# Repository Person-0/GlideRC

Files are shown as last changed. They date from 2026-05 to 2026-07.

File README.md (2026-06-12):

# **GlideRC**
Transforming a 2$ hand-thrown foam glider into an RC Airplane.
<br><br>
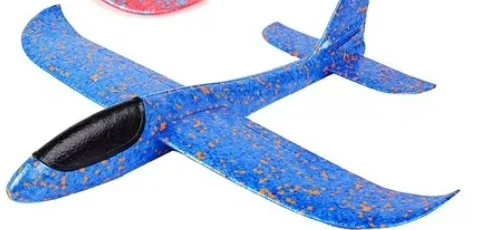
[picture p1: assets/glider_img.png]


## Motivation
I recently discovered this foam glider kit on a toy store while I was travelling. As soon as my eyes saw it, I thought "Why not add a motor and make it fly?" and thus, this project was born. Who would've thought it would take this much effort!

## Parts
Available as [BOM.csv](./bom.csv)
> Might change later on, Depending upon prices and availability.

## Schematics
Done in KiCAD: [Schematics folder](./schematics/)

Since there is no PCB (these are all components wired/soldered together), there are no PCB files. <br>
However, you can still open the schematics in KiCAD, by:
- Opening KiCAD
- Clicking **File** (top left) >> **Open Project**
- Navigating to the the repository's saved destination,
- Opening **/schematics** directory
- Selecting the file `test.kicad_pro`

This will open the schematics in KiCAD for easier viewing!

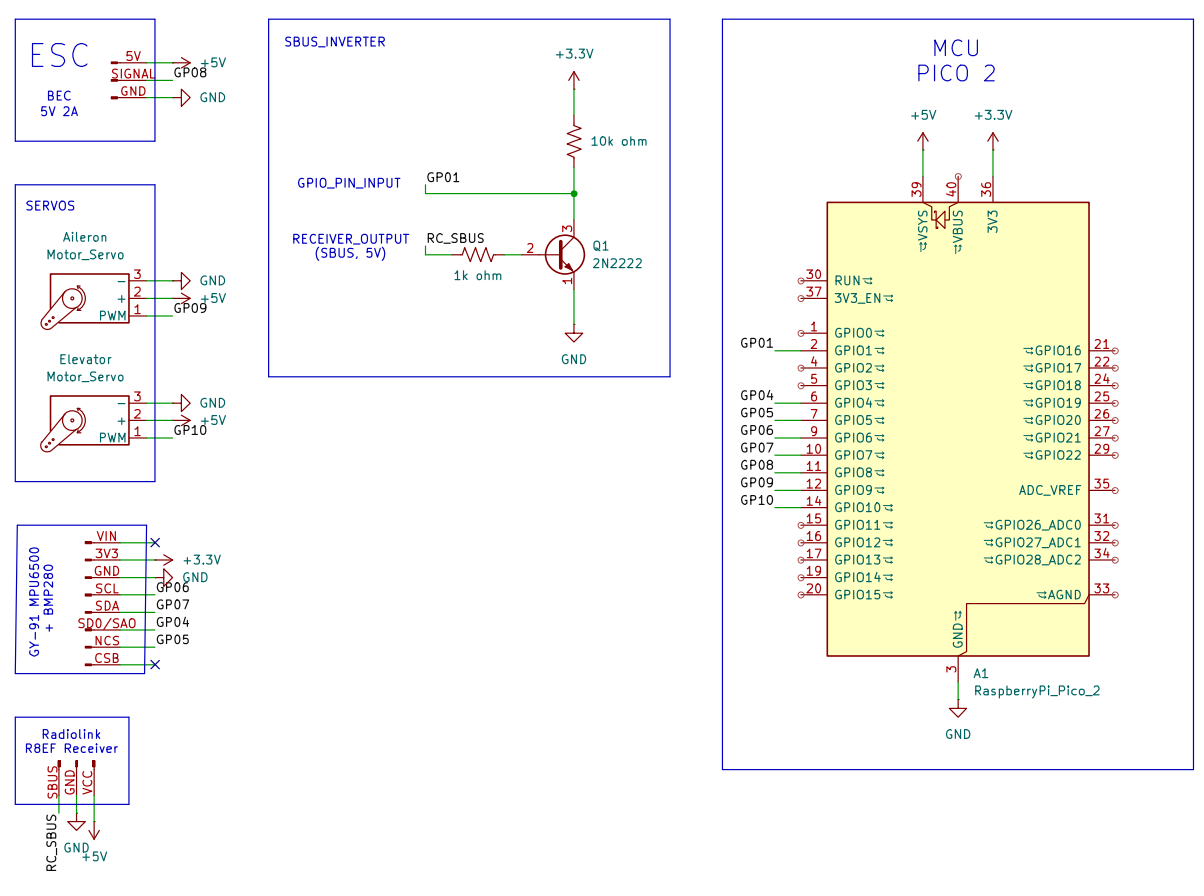
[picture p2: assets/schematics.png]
schematics


## Firmware
In progress: [Firmware folder](./GlideRC_FC_Firmware/)<br>
Please see the readme inside the firmware folder for more info on firmware. 

## Design

Design files (**.step, .dxf** are available in the [`/design` directory](./design/))

> [Sample Foam Glider link](https://www.walmart.com/ip/2-Pack-Glider-Plane-Toys-17-5-Large-Throwing-Foam-Airplane-Dual-Flight-Mode-Flying-Toy-The-Best-Outdoor-Sport-Toy-Gifts-for-Kids/469352630)

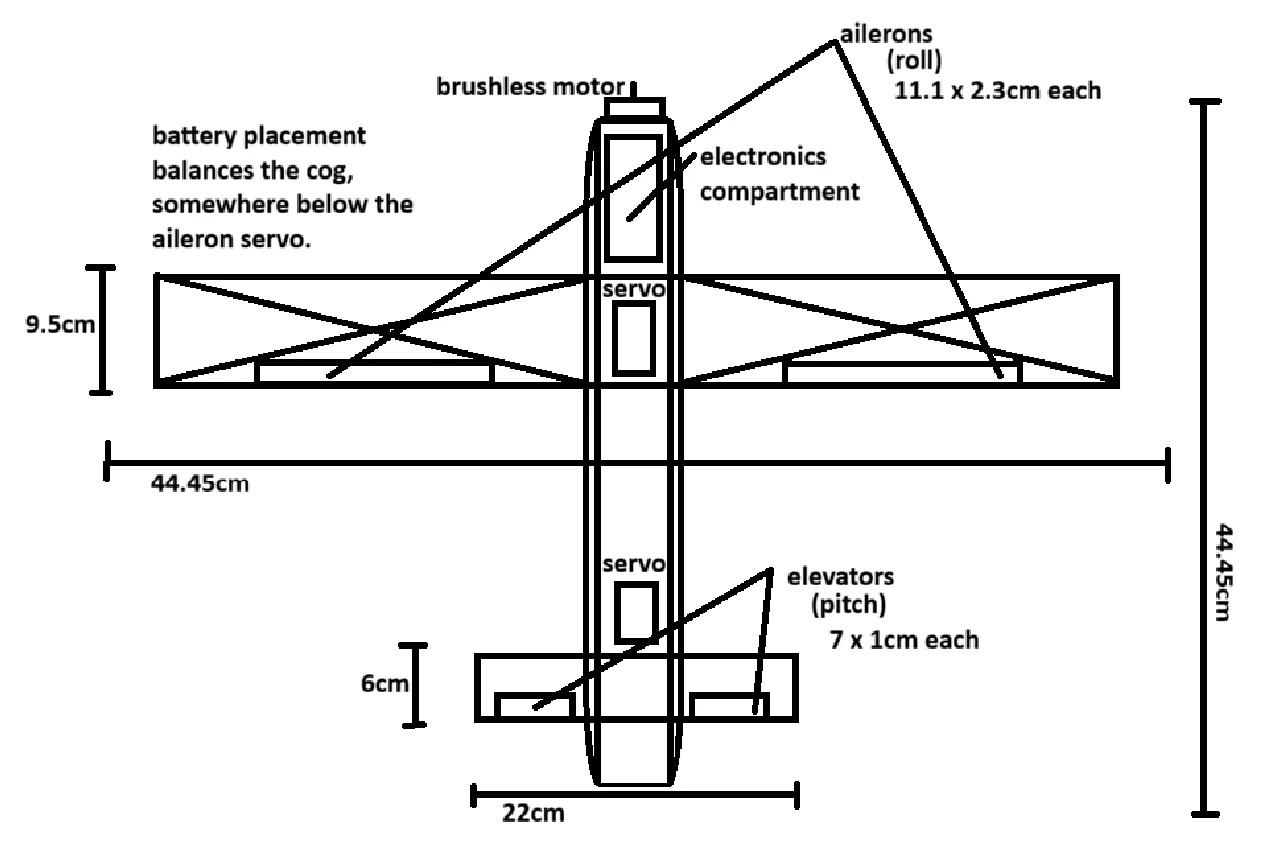
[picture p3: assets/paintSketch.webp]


> Yes, this was designed in paint. I'm sorry. <br>
> "cog" is short for Centre Of Gravity <br>
> see: https://rcplanes.online/index5.htm

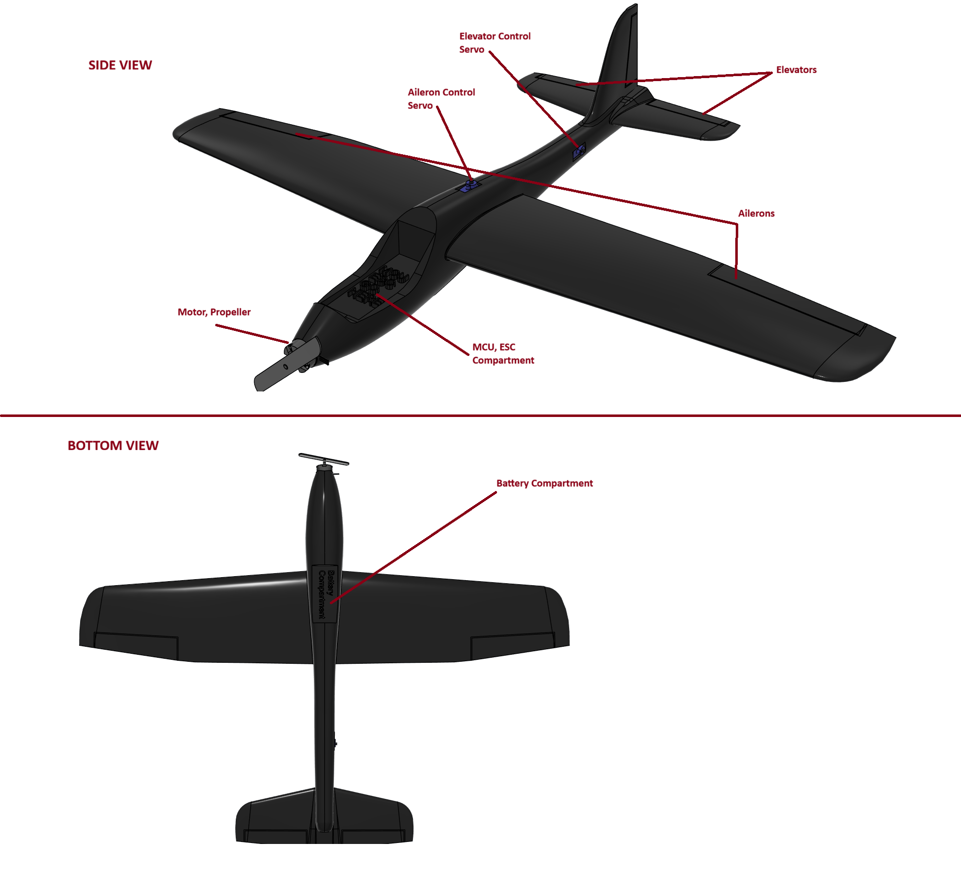
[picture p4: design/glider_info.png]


- The control linkages have not been included as they can only be finalized during the build process.
- The ailerons and elevators will be cut out from the foam wings and taped to the airframe after a 45deg cut so that they can fold up and down to some extent.
- I will be using a vertical mount made of hard cardboard / cutout plastic which will be fixed via a music wire to the servo arm. The mounts will be glued to the ailerons and elevators.

#### CAD Model Credits ([GrabCAD.com](https://grabcad.com/library)):
- [Lidl Glider Basic Replica](https://grabcad.com/library/lidl-glider-basic-replica-1)
- [MT2204 Brushless Motor](https://grabcad.com/library/mt2204-brushless-motor-1)
- [Tower Pro SG92R Micro Servo](https://grabcad.com/library/tower-pro-sg92r-micro-servo-1)

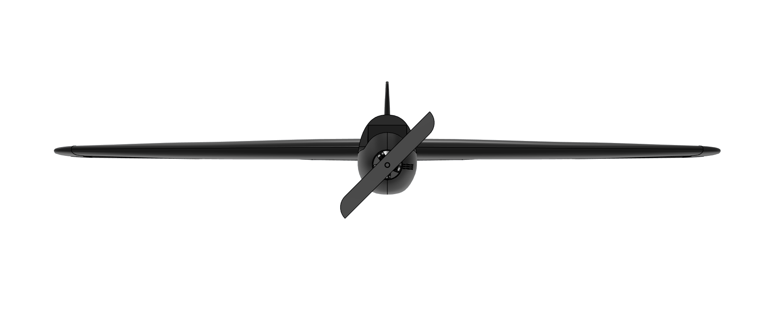
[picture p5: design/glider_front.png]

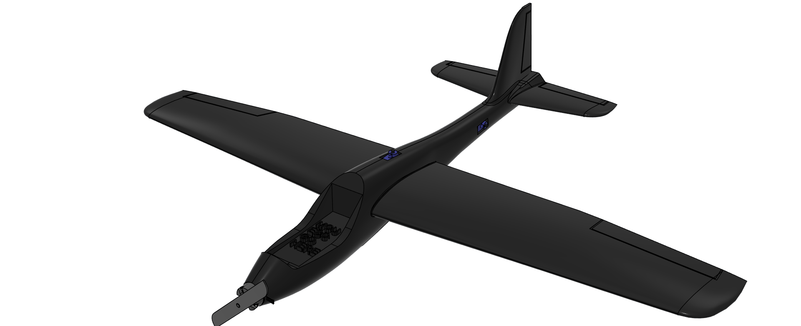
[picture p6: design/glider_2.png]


## What currently works?
- Radio Receiver-to-MCU data transfer
- MCU can control the servos (responsible for controlling the aileron and elevator), the brushless motor
- MCU can access IMU data (gyro, accelerometer)

## What is planned?
- Calibration of values that we actually receive from the components / that actually make the components work
- Stabilization of the aircraft when no updates are received from the transmitter using IMU data to get smooth and stable flight

These goals will not be possible without physical possession of the required components, hence will be done after I receive the components.

## Notes for self
- look into connector types for battery discharge (specs say xt90 but im skeptical of that)
- look into battery charging

## Credits
- [Optimunn/mp92plus](https://github.com/Optimunn/mp92plus/): Really cool MPU9250 (MPU6500) driver for Raspberry pi pico (RP2040) using I2C or SPI.
    - [MIT License](https://github.com/Optimunn/mp92plus/blob/main/LICENSE.md)
    - [located here in firmware](./GlideRC_FC_Firmware/libs/mp92plus/).

## References
- https://rcplanes.online/design.htm
- https://rcplanes.online/index2.htm
- https://rcplanes.online/index5.htm
- https://learn.sparkfun.com/tutorials/voltage-dividers/all
- https://forums.raspberrypi.com/viewtopic.php?t=209958
- https://forums.raspberrypi.com/viewtopic.php?t=285083
- https://www.homemade-circuits.com/how-to-make-logic-gates-using-transistors/
- https://talk.dallasmakerspace.org/t/raspberry-pi-pico-sbus-code-help/79375
- https://docs.micropython.org/en/latest/rp2/quickref.html#quick-reference-for-the-rp2
- https://forums.raspberrypi.com/viewtopic.php?t=88572
- https://forum.arduino.cc/t/mpu6500-6dof-spi-not-working/552645/6
- https://www.raspberrypi.com/documentation/microcontrollers/c_sdk.html
- https://pip-assets.raspberrypi.com/categories/610-raspberry-pi-pico/documents/RP-008276-DS-1-getting-started-with-pico.pdf
- https://pip-assets.raspberrypi.com/categories/609-microcontroller-boards/documents/RP-009085-KB-1-raspberry-pi-pico-c-sdk.pdf
- https://uwarg-docs.atlassian.net/wiki/spaces/efs/pages/2238283817/SBUS+Protocol
- https://www.youtube.com/watch?v=IqLUHj7nJhI
- https://www.w3schools.com/c/index.php
- https://forums.raspberrypi.com/viewtopic.php?t=306053
- https://forums.raspberrypi.com/viewtopic.php?t=339740
- https://www.circuitden.com/blog/16
- https://forums.raspberrypi.com/viewtopic.php?t=370038
- https://www.raspberrypi.com/documentation/pico-sdk/hardware.html#group_hardware_pwm_1pwm_example
- https://www.kpower.com/insight_driver/7471.html/
- https://www.hackster.io/milkgolium/controlling-a-pwm-brushless-esc-with-raspberry-pi-pico-b2d4bb
- https://forums.raspberrypi.com/viewtopic.php?t=320933
- https://github.com/micropython/micropython/blob/d42cba0d22cac812cc5a12f4670010b45932eafa/ports/rp2/machine_spi.c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

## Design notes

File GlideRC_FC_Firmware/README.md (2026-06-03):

# GlideRC Flight Controller Firmware

This is the firmware source code for GlideRC that will be running on the Pico 2 (RP2350).<br>

Currently, It is set to be compiled with RP2040 (Pico) since I had one of those lying around and wanted to test whether it compiles successfully or not.

Since the same code can be compiled for both Pico and Pico 2, It should be easy to switch the board using the "Select Board" option at the bottom right corner of VS Code, if using the [Raspberry Pi Pico extension](https://marketplace.visualstudio.com/items?itemName=raspberry-pi.raspberry-pi-pico) (which is **highly recommended**).

## Tests directory
The tests directory contains tests for the codebase. These tests can be compiled with GCC and ran on a PC and help with combating logical or runtime errors.

To make running tests easier, I use a [`.prayer`](./tests/.prayer) file.
> [pray](https://github.com/Person-0/pray) is a terminal program that you can add in your PATH which runs commands specified in a file in the same directory.

This lets you run commands like:

```bash
pray sbus
```

Instead of typing the full GCC command to build and run the `sbus.c` test.

Available tests:

- `sbus`: Injects custom sbus packets using `inject_sbus_byte` (see [hardware.c](./src/hardware.c)) with proper debug logs.
- `main`: Tests the main code flow by mocking `hardware.c` (see [mocks/hardware.c](./tests/mocks/hardware.c)).

Please do check the [`.prayer`](./tests/.prayer) file too incase I've forgotten to update them here. <br>
Run these tests by cd ing into /tests and running `pray test_name`.

## Compiling / Running the code

This *should* be fairly easy using [VS Code](https://code.visualstudio.com/).

- Install the [Raspberry Pi Pico extension](https://marketplace.visualstudio.com/items?itemName=raspberry-pi.raspberry-pi-pico)
- Directly open the firmware folder
- The extension auto downloads required dependencies and toolchain
- Use the `Compile` or `Run` button at bottom right to Compile the code or Run it respectively.
> Make sure that the board selected matches with what you have.<br>
> Code compiled for Pico (RP2040) will not run on Pico 2 (RP2350) and vice versa.

Also See:
- [Getting started with C/C++ development with Raspberry Pi Pico-series and other
Raspberry Pi microcontroller-based boards](https://pip-assets.raspberrypi.com/categories/610-raspberry-pi-pico/documents/RP-008276-DS-1-getting-started-with-pico.pdf)
- [Raspberry Pi C/C++ SDK](https://www.raspberrypi.com/documentation/microcontrollers/c_sdk.html)

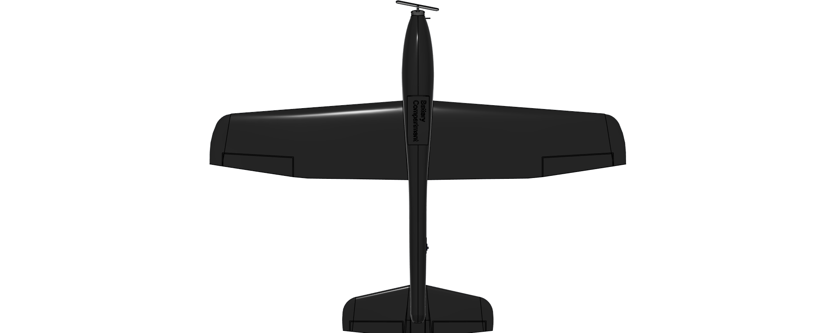
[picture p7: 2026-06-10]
design/glider_bottom.png

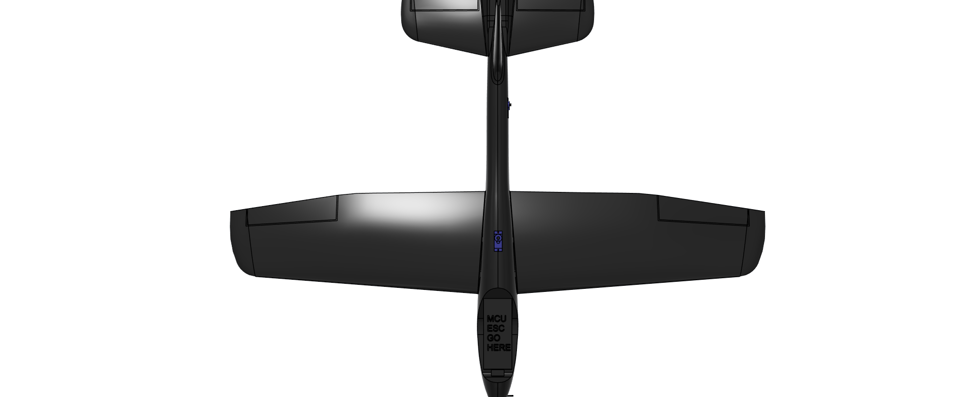
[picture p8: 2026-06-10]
design/glider_top.png

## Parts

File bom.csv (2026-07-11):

 |  | GlideRC: BOM
 |  |  |  | (INR) |  | (INR)
S.No | Product Name | Product Description | Link | Unit Price | Amount | Running Total | Notes | Alternative URL
1 | 2300kv Readytosky Brushless Motor (MT2204) | Brushless Motor | https://robu.in/product/readytosky-mt2204-2300kv-cw-brushless-motor/ | 666 | 1 | 666
2 | EMAX BLHeli-20A ESC | Electronic Speed Controller | https://robu.in/product/emax-blheli-20a-esc/ | 745 | 1 | 745
3 | 2S 7.4V LiPo Battery | LiPo battery | https://genxbattery.com/shop/genx-7-4v-2s-650mah-25c-50c-premium-lipo-lithium-polymer-battery | 953 | 1 | 953 | Already bought | https://www.factoryforward.com/product/orange-600mah-2s-45c90c-74v-lithium-polymer-battery-pack-lipo/
4 | Pro-Range Propellers F5135 Floppy Proppy 2 Blade Propellers 2CW+2CCW - Yellow | Propeller (5135 size) | https://robu.in/product/orange-hd-f5135-floppy-proppy-2-blade-propellers-2cw2ccw-yellow/ | 88 | 1 | 88 | Already bought
5 | Raspberry Pi Pico 2 | Microcontroller | https://robu.in/product/raspberry-pi-pico-2/ | 544 | 1 | 544
6 | TowerPro SG92R Mini Servo Motor (360° Rotation) | Servo | https://techtonics.in/product/tower-pro-sg92r-mini-micro-servo-9g-2-5kg/ | 150 | 2 | 300 | Already bought
7 | MPU6500 6-Axis Gyro Accelerometer DMP Motion Sensor I2C/SPI | IMU | https://robu.in/product/mpu6500-gyroscope-accelerometer-digital-motion-processor-dmp-6-axis-motion-sensor-with-i2c-spi-interface/ | 139 | 1 | 139
8 | Radiolink T8FB BT Remote 2.4GHz 8 Channels Bluetooth RC Remote Transmitter with Receiver R8EF | Radio Transmitter, Receiver Combo | https://rees52.com/products/radiolink-t8fb-bt-remote-2-4ghz-8-channels-bluetooth-rc-remote-transmitter-with-receiver-r8ef-rs6050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 | 4508.8 | 1 | 4508.8
9 | 1k Ohm Resistor | 1k Ohm Resistor | - | 1 | 1 | 1 | Already bought
10 | 10k Ohm Resistor | 10k Ohm Resistor | - | 1 | 1 | 1 | Already bought
 |  |  |  |  | Total: | 7945.8 | Effective Total: 6602.8/-

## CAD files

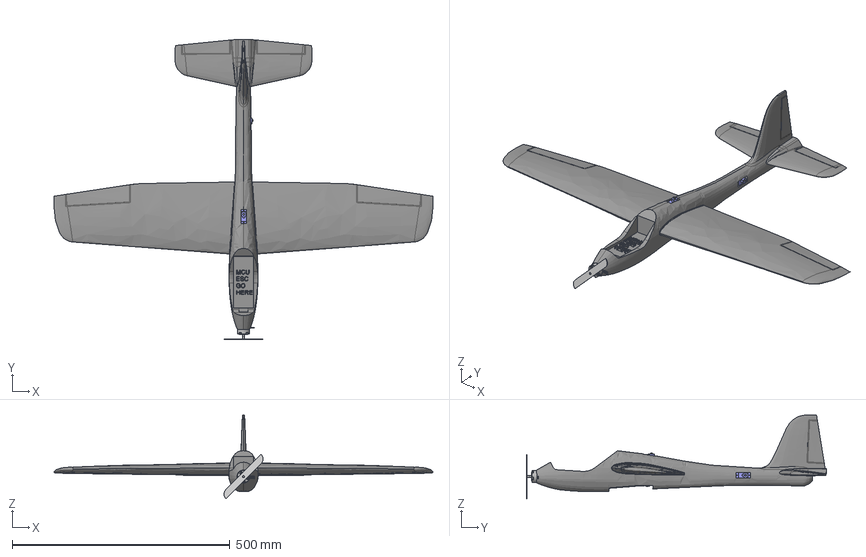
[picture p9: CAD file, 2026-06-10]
design/design.step
870.3 x 689.1 x 192.0 mm

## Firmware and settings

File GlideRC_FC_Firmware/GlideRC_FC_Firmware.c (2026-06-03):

#include <stdio.h>
#include <stdbool.h>
#ifdef ON_FC
    #include "pico/stdlib.h"
    #include "src/hardware.h"
#else
    #include <unistd.h>
    #define sleep_ms(ms) usleep((ms) * 1000)
    #include "tests/mocks/hardware.h"
#endif

#include "src/config.h"

// State variables
bool EXCEPTION_OCCURED = false;
float imu_data[6] = {0.0f, 0.0f, 0.0f, 0.0f, 0.0f, 0.0f};

void sleep_forever() {
    printf("sleeping forever.\n");
    while (1) sleep_ms(1000);
}

void disable_components() {
    disable_motor();
    disable_control_servos();
    disable_imu();
}

void on_error_cleanup() {
    EXCEPTION_OCCURED = true;
    disable_components();
    sleep_forever();
}

// Recieves data from the receiver
void receiver_channel_callback(uint8_t channel, uint16_t value) {

    #ifndef ON_FC
        printf("Channel Callback received %d value for channel %d\n", value, channel);
    #endif

    switch(channel) {

        case CHANNEL_MOTOR:
            set_throttle(value * 100 / 2047);
            break;
        
        case CHANNEL_AILERON:
            set_aileron_angle(value * 180 / 2047);
            break;

        case CHANNEL_ELEVATOR:
            set_elevator_angle(value * 180 / 2047);
            break;
    }

}

int main() {
    #ifdef ON_FC
        stdio_init_all();
    #endif

    printf("> GlideRC_FC_Firmware\n");

    printf("waiting for 1.5s...\n");
    sleep_ms(1500);

    // Receiver
    printf("Setting up SBUS UART port...\n");
    if (setup_sbus_uart() > 0) {
        printf("FATAL Receiver/SBUS error, Exiting.\n");
        on_error_cleanup();
    }
    register_channel_callback(receiver_channel_callback);

    // Control Surfaces
    if (setup_control_servos() > 0) {
        printf("FATAL Control Servos error, Exiting.\n");
        on_error_cleanup();
    }

    // Motor
    if (setup_motor() > 0) {
        printf("FATAL Motor error, Exiting.\n");
        on_error_cleanup();
    }

    // IMU
    if (setup_imu() > 0) {
        printf("FATAL IMU error, Exiting.\n");
        on_error_cleanup();
    }

    // main loop
    while (!EXCEPTION_OCCURED) {
        read_imu(imu_data);
        #ifndef ON_FC
            // === CURRENTLY ONLY LOGGING (phase 1) ===
            printf("imu data read\n");
            printf(
                "Acceleration in G     X = %10.4f,  Y = %10.4f,  Z = %10.4f\n",
                imu_data[0],
                imu_data[1],
                imu_data[2]
            );
            printf("Gyroscope in Deg/s    X = %10.4f,  Y = %10.4f,  Z = %10.4f\n",
                imu_data[3],
                imu_data[4],
                imu_data[5]
            );
        #endif
        sleep_ms(100);
    }

    printf("EXCEPTION_OCCURED, main loop exited\n");
    on_error_cleanup();
}

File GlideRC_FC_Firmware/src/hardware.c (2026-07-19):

#include <stdio.h>
#include <stdint.h>
#ifdef ON_FC
    #include "pico/stdlib.h"
    #include "hardware/uart.h"
    #include "hardware/irq.h"
    #include "hardware/pwm.h"
    #include "hardware/clocks.h"
    #include "../libs/mp92plus/inc/mp92plus.h"
#endif
#include "hardware.h"
#include "config.h"
#include "servo.h"

/*  
=============  
=============
 RECEIVER
 SBUS (already externally inverted)
=============
*/

// SBUS settings
#define SBUS_UART_IRQ SBUS_UART_ID == uart0 ? UART0_IRQ : UART1_IRQ
#define SBUS_BAUD_RATE 100000
#define SBUS_DATA_BITS 8
#define SBUS_STOP_BITS 2
#define SBUS_PARITY UART_PARITY_EVEN

// SBUS parsing
volatile uint8_t sbus_index = 0;
volatile uint8_t sbus_byteCache[25];
volatile uint8_t sbus_bitStore[11];
volatile uint16_t sbus_channels[8];
static void (*channel_callback)(uint8_t, uint16_t) = NULL;

static void parse_sbus_bytes() {
    sbus_channels[0]  = ((sbus_byteCache[1]       | sbus_byteCache[2] << 8)                             & 0x07FF);
    sbus_channels[1]  = ((sbus_byteCache[2]  >> 3 | sbus_byteCache[3] << 5)                             & 0x07FF);
    sbus_channels[2]  = ((sbus_byteCache[3]  >> 6 | sbus_byteCache[4] << 2  | sbus_byteCache[5] << 10)  & 0x07FF);
    sbus_channels[3]  = ((sbus_byteCache[5]  >> 1 | sbus_byteCache[6] << 7)                             & 0x07FF);
    sbus_channels[4]  = ((sbus_byteCache[6]  >> 4 | sbus_byteCache[7] << 4)                             & 0x07FF);
    sbus_channels[5]  = ((sbus_byteCache[7]  >> 7 | sbus_byteCache[8] << 1  | sbus_byteCache[9] << 9)   & 0x07FF);
    sbus_channels[6]  = ((sbus_byteCache[9]  >> 2 | sbus_byteCache[10] << 6)                            & 0x07FF);
    sbus_channels[7]  = ((sbus_byteCache[10] >> 5 | sbus_byteCache[11] << 3)                            & 0x07FF);

    for (uint8_t i = 0; i <= 7; i++) {
        channel_callback(i + 1, sbus_channels[i]);
    }
}

static void on_uart_rx() {
    #ifdef ON_FC
        while (uart_is_readable(SBUS_UART_ID)) {
            uint8_t byte = uart_getc(SBUS_UART_ID);
            if (sbus_index == 0) {
                if (byte != 0x0F) {
                    continue;
                }
            }
            sbus_byteCache[sbus_index] = byte;
            sbus_index++;
            if (sbus_index == 25) {
                parse_sbus_bytes();
                sbus_index = 0;
            }
        }
    #endif
}

int setup_sbus_uart() {
    #ifdef ON_FC
        uart_init(SBUS_UART_ID, SBUS_BAUD_RATE);
        gpio_set_function(SBUS_PIN, GPIO_FUNC_UART);
        uart_set_hw_flow(SBUS_UART_ID, false, false);
        uart_set_format(
            SBUS_UART_ID,
            SBUS_DATA_BITS,
            SBUS_STOP_BITS,
            SBUS_PARITY
        );
        uart_set_fifo_enabled(SBUS_UART_ID, true);
        irq_set_exclusive_handler(SBUS_UART_IRQ, on_uart_rx);
        irq_set_enabled(SBUS_UART_IRQ, true);
        uart_set_irq_enables(SBUS_UART_ID,true,false); // RX only
        printf("SBUS UART port setup correctly\n");
        return 0;
    #endif
    printf("SBUS UART was not setup as not ON_FC\n");
    return 1;
}

void register_channel_callback(void (*callback)(uint8_t, uint16_t)) {
    channel_callback = callback;
    printf("receiver: channel callback registered\n");
}

void inject_sbus_bytes(uint8_t data[25]) {
    for (int i = 0; i < 25; i++) {
        sbus_byteCache[i] = data[i];
    }
    parse_sbus_bytes();
}

/*  
=============
=============
 Control Surfaces
 Servos
=============
*/

int setup_control_servos() {
    if (setup_servo(AILERON_SERVO_PIN, SERVO_FREQ, SERVO_MID) > 0) {
        printf("Aileron setup failed!\n");
        return 1;
    }
    if (setup_servo(ELEVATOR_SERVO_PIN, SERVO_FREQ, SERVO_MID) > 0) {
        printf("Elevator setup failed!\n");
        return 2;
    }
    return 0;
}

void disable_control_servos() {
    disable_servo(AILERON_SERVO_PIN);
    disable_servo(ELEVATOR_SERVO_PIN);
}

/*
 @param angle -> [0, 180]
*/
void set_aileron_angle(int angle) {
    servo_move(AILERON_SERVO_PIN, angle, SERVO_MIN, SERVO_MAX);
}

/*
 @param angle -> [0, 180]
*/
void set_elevator_angle(int angle) {
    servo_move(ELEVATOR_SERVO_PIN, angle, SERVO_MIN, SERVO_MAX);
}

/*
=============
=============
 Brushless Motor
=============
*/

int setup_motor() {
    printf("Setting up motor at Pin %d\n", ESC_SIGNAL_PIN);
    if (setup_servo(ESC_SIGNAL_PIN, ESC_FREQ, ESC_MIN) > 0) {
        printf("Motor setup failed!\n");
        return 1;
    }
    return 0;
}

void disable_motor() {
    printf("Disabling motor at Pin %d\n", ESC_SIGNAL_PIN);
    disable_servo(ESC_SIGNAL_PIN);
}

/*
 @param throttle -> [0, 100]
*/
void set_throttle(uint8_t throttle) {
    throttle = throttle > 100 ? 100 : throttle;
    throttle = (uint8_t)(throttle * ESC_LIMIT);
    servo_move(ESC_SIGNAL_PIN, (throttle * 180) / 100, ESC_MIN, ESC_MAX);
}

/*
=============
=============
 IMU
=============
*/
#ifdef ON_FC
    mpu9250_t IMU;
#endif
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

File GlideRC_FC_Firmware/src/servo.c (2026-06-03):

#include <stdio.h>
#include <stdint.h>
#ifdef ON_FC
    #include "pico/stdlib.h"
    #include "hardware/pwm.h"
    #include "hardware/clocks.h"
#endif
#include "servo.h"

int setup_servo(uint8_t pin, int freq, int pos) {
    printf("setting up servo on pin %d\n", pin);
    #ifdef ON_FC
        gpio_set_function(pin, GPIO_FUNC_PWM);
        uint slice_num = pwm_gpio_to_slice_num(pin);
        uint32_t clock_speed =  clock_get_hz(clk_sys);
        float div = clock_speed / 1000000.0f;
        pwm_set_clkdiv(slice_num, div);
        uint16_t wrap = (1000000.0f / freq) - 1;
        pwm_set_wrap(slice_num, wrap);
        pwm_set_gpio_level(pin, pos);
        pwm_set_enabled(slice_num, true);
        printf("servo setup on pin %d complete\n", pin);
        return 0;
    #else
        printf("servo at pin %d was not setup as not ON_FC\n", pin);
    #endif
    return 1;
}

/*
 @param angle -> [0, 180]
*/
void servo_move(uint8_t pin, int angle, int min, int max) {
    if (angle < 0 || angle > 180) {
        printf(
            "servo_move: angle out of bounds. pin: %d, angle: %d\n",
            pin,
            angle
        );
        return;
    }
    #ifdef ON_FC
        pwm_set_gpio_level(pin, min + (angle * (max - min)) / 180);
    #endif
}

void disable_servo(uint8_t pin) {
    printf("disable_servo: servo at Pin %d has been disabled\n", pin);
    #ifdef ON_FC
        pwm_set_enabled(pwm_gpio_to_slice_num(pin), false);
    #endif
}

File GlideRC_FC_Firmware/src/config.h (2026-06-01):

#ifndef ON_FC
    #define uart0 0
    #define uart1 1
    #define spi0 0
    #define spi1 1
#endif

/*
 Channel
 Control Numbers
*/
#define CHANNEL_MOTOR 0
#define CHANNEL_AILERON 1
#define CHANNEL_ELEVATOR 2

/*
 PIN DEFINITIONS
*/

// Receiver (SBUS protocol)
#define SBUS_PIN 1 // uart rx
#define SBUS_UART_ID uart0

// IMU
#define IMU_SDO 4
#define IMU_NCS 5
#define IMU_SCL 6
#define IMU_SDA 7
#define IMU_SPI spi0

// Motor
#define ESC_SIGNAL_PIN 8
#define ESC_FREQ 50
#define ESC_MIN 1000
#define ESC_MAX 2000
#define ESC_LIMIT 0.25f

// Control surfaces
#define AILERON_SERVO_PIN 9
#define ELEVATOR_SERVO_PIN 10
#define SERVO_FREQ 50
#define SERVO_MIN 1000
#define SERVO_MAX 2000
#define SERVO_MID 1500

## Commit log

2026-05-29 fixed stdint problem when compiling with gcc for tests
    [hardware.c]
2026-05-30 added pin definitions
2026-05-30 added an alternative servo option because the current servo is low in stock
    [bom.csv]
2026-05-30 even better
    [bom.csv]
2026-05-31 moved pin definitions to a separate file that will be shared
2026-05-31 implemented servo control (control surfaces)
2026-06-01 moved servo control to a separate file
2026-06-01 added motor support
2026-06-01 added throttle limit
2026-06-01 added imu support using https://github.com/Optimunn/mp92plus
2026-06-01 better debug logs for imu errors
    [hardware.c]
2026-06-01 imu only log rn
2026-06-10 add blank pcb file
    [test.kicad_pcb]
2026-06-10 added schematic viewing instructions, added design files and preview stuff
    [design.step]
2026-07-11 schematic, bom updates
    [bom.csv, test.kicad_sch]
2026-07-11 update incorrect cost
    [bom.csv]
